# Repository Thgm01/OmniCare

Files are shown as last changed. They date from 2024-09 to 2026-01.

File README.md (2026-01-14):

# OmniCare — Robô Móvel Omnidirecional para Navegação Multi-Andares

> Repositório do Trabalho de Conclusão de Curso de Engenharia de Robôs - OmniCare




<p align="center">
  OmniCare
</p>

---

## 📚 Sumário
- [Visão Geral](#visão-geral)
- [Estrutura do Projeto](#instalação-e-build)
- [Como executar o robô de forma teleoperada](#como-executar-o-robô-de-forma-teleoperada)
- [Como executar o robô para mapear (SLAM ToolBox)](#como-executar-o-robô-para-mapear)
- [Como executar a stack do NAV2](#como-executar-a-stack-do-nav2)

- [Documentações](#documentações)
- [Autores](#👤-autores)
- [Licença](#📝-licença)

---
## Visão Geral

O **OmniCare** é um robô móvel omnidirecional desenvolvido para navegação autônoma em ambientes complexos, com capacidade de deslocamento entre **múltiplos andares** utilizando **elevadores reais**.  
O projeto envolve integração profunda de **ROS 2**, **STM32**, **percepção computacional**, **planejamento de movimento**, **manipulação**, além de uma arquitetura de software robusta baseada em máquina de estados.

## Estrutura do Projeto
 
```bash
.
├── firmware/ # Se concentra todos os firmwares utilizados 
├── hardware/ # Documentação e arquivos da parte eletrônica
├── mechanics/ # Arquivos CAD e modelagem mecânica
├── scripts/
│   ├── record_navigation.sh # Script para gravar a bag de navegação
│   ├── record_vision.sh # Script para gravar a bag de visão
│   ├── scripts.sh # Script para setup do robô
│   ├── setup.sh # Script para setup do robô
│   ├── startup.sh # Script que é rodado quando a jetson "boota"
│   └── sync_omnicare.sh # Script para rsync nootebook --> jetson
│
├── software/src/ # ROS 2 workspace
│   ├── omnicare_behavior/ # Contem o Behavior Manager (FSM)
│   ├── omnicare_bringup/ # Launch principal do OmniCare
│   ├── omnicare_control/ # Controle de movimento do robô
│   ├── omnicare_description/ # Descrição do robô (URDF/XACRO)
│   ├── omnicare_msgs/ # Definição de mensagens customizadas
│   ├── omnicare_navigation/ # Configuração do SLAM e NAV2
│   ├── omnicare_simulation/ # Simulação no Gazebo
│   └── omnicare_vision/ # Módulo de visão computacional
│
└── README.md # Este documento
```

## Instalação e Build

```bash
git clone https://github.com/Thgm01/OmniCare.git
cd OmniCare/software/
rosdep install --from-paths . -y --ignore-src
colcon build --symlink-install
source install/setup.bash
```

## Como executar o robô de forma teleoperada
A teleoperação do OmniCare pode ser feita **diretamente na Jetson** (via SSH) ou **remotamente do seu computador**, desde que ambos utilizem o mesmo **ROS_DOMAIN_ID**.

### **1 - Acesse a Jetson via SSH**
```bash
ssh robot@robot.local
```

### **2 - Inicie o robô (bringup completo)**  
Este comando inicializa os drivers, sensores, TFs e toda a estrutura necessária para operar o robô no mundo real.

```bash
ros2 launch omnicare_bringup load_real_robot.launch.py
```

### **3 - Teleoperação usando teclado**

Você pode rodar o teleop **localmente no seu PC** ou **dentro da Jetson via SSH**.

1. Configure no seu PC o mesmo `ROS_DOMAIN_ID` usado pela Jetson:
```bash
export ROS_DOMAIN_ID=<mesmo_da_jetson>
```

2. Execute o teleop do seu computador:
```bash
ros2 run teleop_twist_keyboard teleop_twist_keyboard
```

## Como executar o robô para mapear
O mapeamento do OmniCare pode ser feita **diretamente na Jetson** (via SSH) ou **remotamente do seu computador**, desde que ambos utilizem o mesmo **ROS_DOMAIN_ID**.

### **1 - Acesse a Jetson via SSH**
```bash
ssh robot@robot.local
```

### **2 - Inicie o robô (bringup completo)**  
Este comando inicializa os drivers, sensores, TFs e toda a estrutura necessária para operar o robô no mundo real.

```bash
ros2 launch omnicare_bringup load_real_robot.launch.py
```

### **3 - Teleoperação usando teclado**

Você pode rodar o teleop **localmente no seu PC** ou **dentro da Jetson via SSH**.

1. Configure no seu PC o mesmo `ROS_DOMAIN_ID` usado pela Jetson:
```bash
export ROS_DOMAIN_ID=<mesmo_da_jetson>
```

2. Execute o teleop do seu computador:
```bash
ros2 run teleop_twist_keyboard teleop_twist_keyboard
```

### **4 - Mapeamento usando o SLAM ToolBox**

Você pode rodar **localmente no seu PC** ou **dentro da Jetson via SSH**.

1. Configure no seu PC o mesmo `ROS_DOMAIN_ID` usado pela Jetson:
```bash
export ROS_DOMAIN_ID=<mesmo_da_jetson>
```

2. Execute o teleop do seu computador:
```bash
ros2 launch navigation_pkg mapping_slam_toolbox.launch.py
```

3. Após rodar o launch do SLAM ToolBox, abra o RViz2 no seu computador com essa configuração
```bash
software/src/omnicare_navigation/navigation_pkg/config/rviz/mapping_cartographer.rviz
```

## Como executar a stack do NAV2
A navegação do OmniCare é preferivel ser feita **em um notebook externo** por conta do processamento, é necessário que ambos utilizem o mesmo **ROS_DOMAIN_ID**.

### **1 - Acesse a Jetson via SSH**
```bash
ssh robot@robot.local
```

### **2 - Inicie o robô (bringup completo)**  
Este comando inicializa os drivers, sensores, TFs e toda a estrutura necessária para operar o robô no mundo real.

```bash
ros2 launch omnicare_bringup load_real_robot.launch.py
```

### **3 - Navegando usando a stack do NAV2**

É recomendado rodar **localmente no seu PC** por conta do processamento pesado de CPU.

1. Configure no seu PC o mesmo `ROS_DOMAIN_ID` usado pela Jetson:
```bash
export ROS_DOMAIN_ID=<mesmo_da_jetson>
```

2. Execute o teleop do seu computador:
```bash
ros2 launch navigation_pkg navigation2.launch.py
```

3. Após rodar o launch do NAV2, abra o RViz2 no seu computador com essa configuração
```bash
software/src/omnicare_navigation/navigation_pkg/config/rviz/navigation.rviz
``` 
## Documentações

A documentação do OmniCare está organizada de forma modular, abrangendo mecânica, hardware, firmware e software.  
Cada módulo possui sua própria pasta dedicada, permitindo uma navegação clara e objetiva.

---

### Documentação Mecânica
A pasta [`mechanics/`](mechanics/) contém:

- Modelos CAD completos do robô  
- Estrutura da base omnidirecional  
- Projeto do manipulador linear  
- Especificações de motores, rodas e sensores mecânicos  

---

### Documentação Hardware
A pasta [`hardware/`](hardware/) contém:

- Esquemáticos elétricos  
- Layout da arquitetura eletrônica  
- Detalhamento dos módulos embarcados  

---

### Documentação Software (ROS 2)

O software do OmniCare é composto por múltiplos pacotes ROS 2, cada um contendo suas características e funcionalidades.

### Pacotes ROS 2
---

### 🔹 [omnicare_behavior](software/src/omnicare_behavior/)
O pacote **omnicare_behavior** contem a máquina de estados responsável por coordenar toda a missão do robô. É ele quem controla o fluxo completo da navegação entre diferentes andares, integrando percepção, navegação, manipulação e troca de mapas. O Behavior Manager decide quando iniciar a navegação, alinhar ao elevador, interagir com o painel, trocar de mapa no momento correto e retomar o trajeto até o destino final.

---

### 🔹 [omnicare_bringup](software/src/omnicare_bringup/)
O pacote **omnicare_bringup** é responsável por inicializar todo o sistema do robô, tanto no ambiente real quanto no simulador. Ele carrega automaticamente os módulos essenciais, incluindo o ROS 2 Control, a comunicação com os microcontroladores (STM32), e os sensores embarcados, como o LiDAR. Em resumo, é o pacote que prepara todo o ecossistema do OmniCare para operação, garantindo que hardware, drivers e interfaces estejam corretamente configurados antes da execução dos módulos de navegação e comportamento.

---

### 🔹 [omnicare_control](software/src/omnicare_control/)
O **omnicare_control** é um conjunto de três pacotes que implementa toda a camada de controle de baixo nível do OmniCare. Ele integra a cinemática, a dinâmica e as interfaces de hardware do robô, permitindo que o sistema execute movimentos omnidirecionais de forma precisa e compatível com o ROS 2 Control e o movimento do manipulador.

---

### 🔹 [omnicare_description](software/src/omnicare_description/)

O **omnicare_description** é o pacote responsável por reunir toda a descrição física do OmniCare, incluindo o seu URDF completo, as malhas utilizadas para visualização e os plugins necessários para simulação e controle. Ele define a estrutura mecânica, sensores, atuadores e juntas do robô, garantindo que sua representação virtual seja fiel ao modelo real. Além disso, integra os plugins do Gazebo para simulação física e dos ROS 2 Control para conexão com controladores e interfaces de hardware, servindo como a base unificada para visualização, simulação e operação do robô tanto no ambiente virtual quanto no mundo real.

---

### 🔹 [omnicare_hri](software/src/omnicare_hri/)

O **omnicare_hri** engloba os pacotes dedicados à Interação Humano–Robô (HRI) no OmniCare. Ele é composto por um módulo responsável pelas animações faciais do robô — incluindo expressões exibidas na tela frontal, LEDs de sinalização e o buzzer — permitindo que o robô comunique estados e ações de forma mais amigável ao usuário. Complementando essa funcionalidade, o segundo pacote implementa uma interface para um controle remoto baseado em ESP32, possibilitando acionar comandos do robô de maneira simples.

---

### 🔹 [omnicare_msgs](software/src/omnicare_msgs/)

O **omnicare_msgs** é o pacote responsável por definir todas as mensagens customizadas utilizadas pelos diferentes módulos do OmniCare, incluindo topics, services e actions. Ele centraliza estruturas de dados específicas do projeto — como comandos de movimento, estados do comportamento, mensagens do manipulador, sinais de expressão e eventos da navegação multi-andares — garantindo comunicação padronizada e consistente entre os diversos nós do sistema.

---

### 🔹 [omnicare_navigation](software/src/omnicare_navigation/)
O **omnicare_navigation** reúne um conjunto de pacotes responsáveis por toda a camada de navegação do OmniCare. Ele inclui o pacote do LiDAR, que fornece os dados primários de percepção espacial, e o pacote da IMU, atualmente integrado ao sistema mas ainda não utilizado diretamente na navegação. O núcleo deste módulo é o navigation_pkg, que contém os launch files do NAV2, incluindo configuração de planejadores, BTs e parâmetros de navegação. Além disso, o conjunto oferece launchs específicos para mapeamento do ambiente, permitindo a criação e atualização de mapas utilizados pelo Nav2 e pelo AMCL.

---

### 🔹 [omnicare_simulation](software/src/omnicare_simulation/)
O **omnicare_simulation** reúne todos os recursos necessários para a simulação completa do OmniCare no Gazebo, incluindo launch files dedicados para iniciar o robô, seus sensores e o ambiente virtual. Além disso, o pacote implementa serviços auxiliares de teletransporte dentro do simulador para validação da navegação de multi-andares.

---

### 🔹 [omnicare_vision](software/src/omnicare_vision/)
O **omnicare_vision** concentra todos os pacotes relacionados ao sistema de visão do OmniCare. Ele inclui o usb_cam, que atua como driver da câmera e fornece o fluxo de imagens bruto; o floor_detector, responsável por realizar a inferência sobre o display do elevador e classificar corretamente o andar atual; e o dataset_generator, um pacote auxiliar utilizado para gerar datasets automaticamente a partir de rosbags.

## 👤 Autores

**Lucas Lagoeiro**  
Graduando em Engenharia de Robôs – Centro Universitário FEI  
Área: Programação e Elétrica   
[LinkedIn](https://www.linkedin.com/in/llagoeiro/) • [GitHub](https://github.com/LucasLagoeiro)

**Thiago Moura**  
Graduando em Engenharia de Automação e Controle – Centro Universitário FEI  
Área: Programação e Elétrica  
[LinkedIn](https://www.linkedin.com/in/thiago-t-moura/) • [GitHub](https://github.com/Thgm01)

**Massiel Blandy**  
Graduando em Engenharia de Automação e Controle – Centro Universitário FEI  
Área: Programação  
[LinkedIn](https://www.linkedin.com/in/massiel-blandy-ram%C3%B3n-65214829a/) • [GitHub](https://github.com/massiblandy)

**Júlia Hernandes**  
Graduanda em Engenharia Elétrica – Centro Universitário FEI  
Área: Elétrica  
[LinkedIn](https://www.linkedin.com/in/j%C3%BAlia-gagliera-hernandes-40545b221/) 

**Gustavo Rosell**  
Graduando em Engenharia de Automação e Controle – Centro Universitário FEI  
Área: Mecânica  
[LinkedIn](https://linkedin.com/in/gustavo-rosell) 

**Leonardo Quirino**  
Graduando em Engenharia de Robôs – Centro Universitário FEI  
Área: Mecânica  
[LinkedIn](https://www.linkedin.com/in/leonardo-quirino-353486218/)

## 📝 Licença

Este projeto está licenciado sob a Licença MIT.

Isso significa que você pode usar, copiar, modificar, mesclar, publicar, distribuir, sublicenciar e/ou vender cópias do software, desde que mantenha o aviso de copyright e a permissão de licença incluídos em todas as cópias ou partes substanciais do software.

Para mais detalhes, consulte o arquivo [LICENSE](LICENSE).

## 📝 TODO — Documentação dos Pacotes

A seguir está o checklist de pacotes do OmniCare que terão documentação detalhada seguindo o mesmo padrão adotado no `omnicare_behavior`.

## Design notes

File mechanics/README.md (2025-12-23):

# OmniCare Mechanics

O OmniCare foi projetado para operar em ambientes hospitalares, com ênfase em mobilidade omnidirecional, modularidade estrutural e compatibilidade com normas de circulação. 
A base possui arquitetura circular, construída com chapas de MDF e perfis de alumínio, permitindo a integração do sistema elétrico, do manipulador e de um compartimento de carga modular. 
O manipulador foi desenvolvido para interação com elevadores, contando com graus de liberdade translacionais e rotacional no efetuador final.

Nesta seção você encontrará todos os materiais relacionados ao desenvolvimento mecânico do robô, incluindo:

- Modelos CAD completos do robô;
- Estrutura da base omnidirecional;
- Projeto do manipulador;
- Especificações de motores e rodas.

Esses arquivos permitem entender a composição estrutural do robô, seus componentes principais e a lógica de montagem mecânica.

Os arquivos de montagem estão separadas nas cinco seguintes pastas: Base, Carga, Fixação, LED, Manipulador. 

### Base

A pasta base contem todas as peças que compõe a base omnidirecional do OmniCare. Nesta pasta estão todos os modelos das chapas MDF (pasta MDF) e dos perfis de alumínio (pasta Perfil de alumínio) usados para montar a estrutura do robô, além das chapas de alumínio que contornam o robô (pasta Alumínio. O modelo das rodas omnidirecionais estão contidos dentro desta pasta (pasta Roda), assim como os motores utilizados para seu acionamento (pasta Motor). Todas as peças especiais, que precisaram ser feitas por meio de impressão 3D, estão contidas nesta pasta (pasta Impresso). E, por fim, a pasta conta com modelos 3D de todos os itens comprados do robô, como o LiDAR e as baterias.

### Carga

A pasta carga é a responsável por guardar os modelos 3D do compartimento de carga do OmniCare. Sua divisão de subpastas é igual a divisão da pasta Base.

### LED

Dentro da pasta LED estão todos os arquivos utilizados para a confecção do difusor de LED do OmniCare. Mas não somente os modelos 3D estão nesta pasta, há dois arquivos de pesquisas referentes a interações humano-robô que discutem a importância das interações visuais (luzes) e interações auditivas (emissões de sons de alerta), essas pesquisas são de suma importância para a IHR do OmniCare.

### Manipulador

A pasta Manipulador está dividida em 4 subpastas principais. Dentro da pasta Estrutura, estão todas as peças desenvolvidas para o corpo do manipulador e as peças responsáveis pelo movimento vertical do manipulador. Já na pasta Elevador, estão as peças feitas para a base que acompanha o movimento vertical, base essa responsável por realizar o movimento horizontal do manipulador. A pasta Ferramenta conta com as peças feitas para a confecção da ferramenta, responsável por segurar a câmera do OmniCare e por pressionar os botões do elevador. A pasta Elementos de fixação conta com todos os parafusos, porcas e arruelas usadas para a fixação de todas as partes do manipulador.

### Fixação

Todos os elementos de fixação utilizados no OmniCare, desde parafusos à cantoneiras, se encontram dentro da pasta Fixação. Nesta pasta, também é possível encontrar os arquivos das normas dos itens, além das tabelas de dimensões.

O acesso às modelagens e documentos está disponível no link abaixo:
https://drive.google.com/drive/folders/1Ufkg-2wcXs-KffQ5NBY0fZA2kzGGDrn_?usp=drive_link

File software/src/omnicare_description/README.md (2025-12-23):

# OmniCare Description (`omnicare_description`)

O **`omnicare_description`** é o pacote responsável por concentrar toda a **descrição física e estrutural do OmniCare**, servindo como a base para **visualização, simulação e controle** do robô.  
Ele define como o robô “existe” dentro do ecossistema ROS 2, garantindo consistência entre o modelo físico, o simulador e os controladores.

---

## Considerações

A descrição do robô foi projetada para atender simultaneamente aos seguintes cenários:

- Visualização no **RViz**;
- Simulação física no **Gazebo**;
- Integração com o **ROS 2 Control**;
- Operação no robô real.

Para isso, o pacote foi estruturado de forma modular, permitindo ativar ou desativar plugins conforme o modo de execução (simulação ou real), sem a necessidade de manter múltiplas descrições distintas.

---

## Arquitetura Geral

O `omnicare_description` atua como o **núcleo descritivo** do sistema, fornecendo:

- Estrutura mecânica do robô;
- Relações cinemáticas entre links e juntas;
- Definição de sensores e atuadores;
- Interfaces necessárias para controle e simulação.

Todos os outros pacotes — navegação, controle, simulação e bringup — dependem diretamente dessa descrição. Ele segue essa estrutura de arquivos:
```bash
omnicare_description/
├─ launch/
│  └─ display.launch.py
│     └─ Launch para visualização do robô no RViz
│        (robot_state_publisher + joint_state_publisher + RViz)
│
├─ config/
│  └─ display.rviz
│     └─ Configuração padrão do RViz utilizada no display.launch.py
│
├─ urdf/
│  ├─ robot.xacro
│  │  └─ Arquivo principal da descrição do OmniCare
│  │     Define links, joints e inclui módulos conforme o modo
│  │     (simulação ou robô real)
│  │
│  ├─ robot.gazebo
│  │  └─ Plugins para simulação no Gazebo
│  │     (sensores e parâmetros físicos)
│  │
│  ├─ ros2_control.xacro
│  │  └─ Integração do robô real com o ROS 2 Control
│  │     Define hardware interface, joints e interfaces de comando
│  │
│  ├─ gazebo_control.xacro
│  │  └─ Integração do robô simulado com o ROS 2 Control
│  │     Utiliza o plugin gazebo_ros2_control (ñ utilizado)
│  │
│  └─ camera.xacro
│     └─ Definição dos frames e da geometria da câmera do robô
│
└─ meshes/
   └─ (Arquivos de malha e sensores)
      └─ Modelos 3D utilizados pelo URDF para visualização e colisão
```

---

## URDF / Xacro

A descrição do OmniCare é construída utilizando **URDF com Xacro**, o que permite:

- Parametrização de componentes;
- Reutilização de macros;
- Diferenciação entre **modo simulado** e **modo real**;
- Organização clara do modelo do robô.

O arquivo Xacro principal é responsável por incluir:
- Base omnidirecional;
- Rodas e juntas;
- Manipulador frontal;
- Sensores (ex.: LiDAR);
- Interfaces de controle.

---

## Integração com ROS 2 Control

A integração com o ROS 2 Control é definida diretamente no URDF por meio da tag `<ros2_control>`.  
Essa seção especifica como o sistema de controle se comunica com o hardware real, quais juntas são controladas e quais interfaces de comando e estado são utilizadas.

---

## Definição do Sistema ROS 2 Control

```xml
<ros2_control name="RealRobot" type="system">
```

- **`name="RealRobot"`**: identifica o sistema de controle do robô real.
- **`type="system"`**: indica que o plugin implementa leitura de estados e escrita de comandos diretamente no hardware.

---

## Hardware Interface

```xml
<hardware>
    <plugin>omnidrive_stm32/OmniDriveSTM32</plugin>
```

O plugin **`OmniDriveSTM32`** (encontrado no **`omnicare_control/omnidrive_stm32/`**) implementa a Hardware Interface do ROS 2 Control, sendo responsável por:

- Enviar comandos de velocidade ao STM32;
- Ler feedback dos encoders;
- Atualizar os estados das juntas no ROS 2.

---

## Parâmetros de Hardware

```xml
<param name="left_wheel_name">wheel2_speed</param>
<param name="right_wheel_name">wheel1_speed</param>
<param name="back_wheel_name">wheel3_speed</param>
```

Mapeamento entre juntas do URDF e rodas físicas do robô, essa informação tem que bater com o arquivo de configuração do controlador ([omnidirectional_controllers](../omnicare_control/omnidirectional_controllers/config/omnidirectional_controller.yaml)).

```xml
<param name="loop_rate">30</param>
```

Frequência de atualização da interface (Hz).

```xml
<param name="device">/dev/usb-user</param>
<param name="baud_rate">115200</param>
<param name="timeout_ms">1000</param>
```

Parâmetros da comunicação serial com o STM32.

```xml
<param name="enc_counts_per_rev">12770</param>
```

Resolução do encoder utilizada para cálculo de velocidade e posição (relacionado ao nosso motor - se trocar, vai precisar alterar esse parâmetro).

---

## Definição das Juntas

Cada roda é definida como uma junta controlada:

```xml
<joint name="wheel1_speed">
    <command_interface name="velocity" />
    <state_interface name="position" />
    <state_interface name="velocity" />
</joint>
```

- **Command Interface**: `velocity` (utilizando na função de **write** do [Hardware Inteface](../omnicare_control/omnidrive_stm32/hardware/diffbot_system.cpp))
- **State Interfaces**: `position` e `velocity` (utilizando na função de **read** do [Hardware Inteface](../omnicare_control/omnidrive_stm32/hardware/diffbot_system.cpp))

O mesmo padrão é utilizado para as três rodas omnidirecionais.

---

## Fluxo de Funcionamento

1. Nav2, teleoperação ou Behavior Manager publicam `cmd_vel`;
2. O `controller_manager` recebe o comando;
3. O controlador omnidirecional calcula:
   - cinemática;
   - odometria;
   - velocidades individuais das rodas;
4. O ROS 2 Control envia comandos para o STM32;
5. O STM32 executa o controle de baixo nível (PID/PWM);
6. O feedback dos encoders retorna ao ROS 2;
7. Estados e odometria alimentam Nav2 e localização.

---
## Integração com Gazebo

Para simulação, o `omnicare_description` inclui **plugins do Gazebo** responsáveis por:

- Simular sensores (LiDAR, estados das juntas, etc.);
- Aplicar dinâmica e física ao modelo;
- Permitir interação com o ambiente virtual.

Esses plugins são habilitados apenas quando o robô é executado em modo simulado, mantendo a descrição compatível com o robô real.

---

## Visualização no RViz

A descrição fornecida por este pacote é utilizada diretamente pelo **RViz**, permitindo:

- Visualização da geometria do robô;
- Acompanhamento da árvore de TFs;
- Monitoramento do estado das juntas;
- Depuração visual durante desenvolvimento e testes.

Para conseguir visualiza-lo basta apenas rodar:
```bash
ros2 launch omnicare_description display.launch.py
```

---

## Integração com Outros Pacotes

O `omnicare_description` é utilizado diretamente por:

- **`omnicare_bringup`** — carregamento da descrição durante a inicialização;
- **`omnicare_control`** — definição das juntas e transmissões para controle;
- **`omnicare_simulation`** — spawn do robô no Gazebo;
- **`omnicare_navigation`** — referência de frames (`base_link`, `odom`, `map`);
s
---

## Papel no Sistema

O **`omnicare_description`** é o pacote que garante que **todas as camadas do OmniCare falem a mesma “língua física”**.  
Ele assegura que o robô visto no simulador, controlado pelo ROS 2 Control e operando no mundo real compartilhe a mesma estrutura, cinemática e referências, sendo essencial para a robustez e a escalabilidade do sistema.

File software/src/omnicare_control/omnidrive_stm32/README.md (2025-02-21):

# omnidrive_stm32

This node is designed to provide a ros2_control hardware interface for an Arduino running firmware from `ros_arduino_bridge`.
It is designed to be used with a `diff_drive_controller` from `ros2_control`.
It is expected to communicate via serial and to have two motors, each with velocity control and position/velocity feedback.

It is based on the diffbot example from [ros2_control demos](https://github.com/ros-controls/ros2_control_demos/tree/master/example_2).

For a tutorial on how to develop a hardware interface like this, check out the video below:

https://youtu.be/J02jEKawE5U

## To Do

- [ ] Document changes from earlier versions
- [ ] Document usage and parameters
- [ ] Clean up remaining connections to original demo code
- [ ] Add license etc (in the meantime, do whatever you want with it)

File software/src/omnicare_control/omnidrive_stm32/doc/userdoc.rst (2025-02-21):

.. _ros2_control_demos_example_2_userdoc:

*********
DiffBot
*********

*DiffBot*, or ''Differential Mobile Robot'', is a simple mobile base with differential drive.
The robot is basically a box moving according to differential drive kinematics.

For *example_2*, the hardware interface plugin is implemented having only one interface.

- The communication is done using proprietary API to communicate with the robot control box.
- Data for all joints is exchanged at once.

The *DiffBot* URDF files can be found in ``description/urdf`` folder.

Tutorial steps
--------------------------

1. To check that *DiffBot* description is working properly use following launch commands

   .. code-block:: shell

    ros2 launch omnidrive_stm32 view_robot.launch.py

   .. warning::
    Getting the following output in terminal is OK: ``Warning: Invalid frame ID "odom" passed to canTransform argument target_frame - frame does not exist``.
    This happens because ``joint_state_publisher_gui`` node need some time to start.

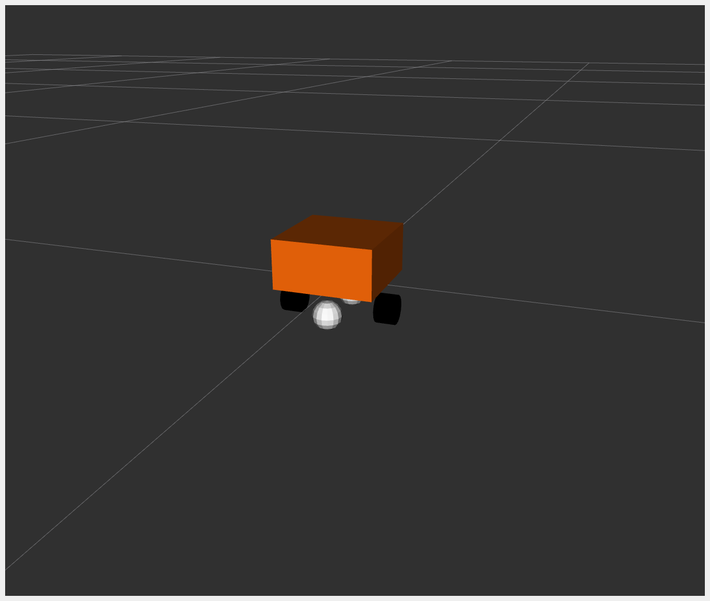
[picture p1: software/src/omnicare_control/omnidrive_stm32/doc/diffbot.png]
Differential Mobile Robot
   

2. To start *DiffBot* example open a terminal, source your ROS2-workspace and execute its launch file with

   .. code-block:: shell

    ros2 launch omnidrive_stm32 diffbot.launch.py

   The launch file loads and starts the robot hardware, controllers and opens *RViz*.
   In the starting terminal you will see a lot of output from the hardware implementation showing its internal states.
   This excessive printing is only added for demonstration. In general, printing to the terminal should be avoided as much as possible in a hardware interface implementation.

   If you can see an orange box in *RViz* everything has started properly.
   Still, to be sure, let's introspect the control system before moving *DiffBot*.

3. Check if the hardware interface loaded properly, by opening another terminal and executing

   .. code-block:: shell

    ros2 control list_hardware_interfaces

   You should get

   .. code-block:: shell

    command interfaces
          left_wheel_joint/velocity [available] [claimed]
          right_wheel_joint/velocity [available] [claimed]
    state interfaces
          left_wheel_joint/position
          left_wheel_joint/velocity
          right_wheel_joint/position
          right_wheel_joint/velocity

   The ``[claimed]`` marker on command interfaces means that a controller has access to command *DiffBot*.

4. Check if controllers are running

   .. code-block:: shell

    ros2 control list_controllers

   You should get

   .. code-block:: shell

    diffbot_base_controller[diff_drive_controller/DiffDriveController] active
    joint_state_broadcaster[joint_state_broadcaster/JointStateBroadcaster] active

5. If everything is fine, now you can send a command to *Diff Drive Controller* using ROS 2 CLI interface:

   .. code-block:: shell

    ros2 topic pub --rate 30 /diffbot_base_controller/cmd_vel_unstamped geometry_msgs/msg/Twist "linear:
      x: 0.7
      y: 0.0
      z: 0.0
    angular:
      x: 0.0
      y: 0.0
      z: 1.0"

   You should now see an orange box circling in *RViz*.
   Also, you should see changing states in the terminal where launch file is started.

   .. code-block:: shell

    [OmniDriveSTM32]: Got command 43.33333 for 'left_wheel_joint'!
    [OmniDriveSTM32]: Got command 50.00000 for 'right_wheel_joint'!

Files used for this demos
#########################

  - Launch file: `diffbot.launch.py <https://github.com/ros-controls/ros2_control_demos/tree/master/example_2/bringup/launch/diffbot.launch.py>`__
  - Controllers yaml: `diffbot_controllers.yaml <https://github.com/ros-controls/ros2_control_demos/tree/master/example_2/bringup/config/diffbot_controllers.yaml>`__
  - URDF file: `diffbot.urdf.xacro <https://github.com/ros-controls/ros2_control_demos/tree/master/example_2/description/urdf/diffbot.urdf.xacro>`__

    + Description: `diffbot_description.urdf.xacro <https://github.com/ros-controls/ros2_control_demos/tree/master/example_2/description/urdf/diffbot_description.urdf.xacro>`__
    + ``ros2_control`` tag: `diffbot.ros2_control.xacro <https://github.com/ros-controls/ros2_control_demos/tree/master/example_2/description/ros2_control/diffbot.ros2_control.xacro>`__

  - RViz configuration: `diffbot.rviz <https://github.com/ros-controls/ros2_control_demos/tree/master/example_2/description/rviz/diffbot.rviz>`__

  - Hardware interface plugin: `diffbot_system.cpp <https://github.com/ros-controls/ros2_control_demos/tree/master/example_2/hardware/diffbot_system.cpp>`__

Controllers from this demo
##########################

- ``Joint State Broadcaster`` (`ros2_controllers repository <https://github.com/ros-controls/ros2_controllers/tree/master/joint_state_broadcaster>`__): `doc <https://control.ros.org/master/doc/ros2_controllers/joint_state_broadcaster/doc/userdoc.html>`__
- ``Diff Drive Controller`` (`ros2_controllers repository <https://github.com/ros-controls/ros2_controllers/tree/master/diff_drive_controller>`__): `doc <https://control.ros.org/master/doc/ros2_controllers/diff_drive_controller/doc/userdoc.html>`__

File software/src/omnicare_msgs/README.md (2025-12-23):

# OmniCare Messages (`omnicare_msgs`)

O **`omnicare_msgs`** é o pacote responsável por centralizar todas as **mensagens customizadas** utilizadas no projeto OmniCare.  
Ele define os tipos de dados usados para comunicação entre nós ROS 2 por meio de **topics**, **services** e **actions**, garantindo padronização, clareza e integração entre os diferentes subsistemas do robô.

---

## Considerações

Em um sistema robótico complexo como o OmniCare, a comunicação entre módulos precisa ser:

- Bem definida;
- Consistente ao longo de todo o projeto;
- Fácil de manter e expandir.

Por esse motivo, todas as mensagens customizadas foram agrupadas em um único pacote, evitando duplicações e facilitando a evolução do sistema.

---

## Tipos de Interfaces

O `omnicare_msgs` contém três tipos principais de definições:

### Messages (`msg`)
Mensagens utilizadas para comunicação assíncrona via tópicos, geralmente para:
- Estados do robô;
- Comandos simples;
- Publicação contínua de informações.

---

### Services (`srv`)
Serviços utilizados para chamadas síncronas, quando é necessário:
- Enviar uma requisição;
- Aguardar uma resposta imediata.

São comuns em comandos pontuais, como inicializações ou mudanças de estado.

A maioria dos serviços criados são utilizadas mensagens customizadas para aumentar a flexibilidade do que mandar.

---

### Actions (`action`)
Actions são utilizadas para operações de **longa duração**, permitindo:
- Envio de um objetivo (*goal*);
- Recebimento de *feedback* contínuo;
- Notificação de conclusão (*result*).

No OmniCare, actions são fundamentais para tarefas como:
- Navegação multi-andares;

---

## Integração com Outros Pacotes

Este pacote é utilizado por praticamente todo o sistema, incluindo:

- **`omnicare_behavior`** — definição de actions para missões e estados;
- **`omnicare_navigation`** — troca de informações de navegação;
- **`omnicare_control`** — comandos e estados de controle;
- **`omnicare_expression`** — acionamento de expressões e sinalizações;
- **`omnicare_hri`** — interação humano–robô.

---

## Papel no Sistema

O **`omnicare_msgs`** garante que todos os módulos do OmniCare se comuniquem de forma clara, consistente e organizada.  
Ele é um elemento fundamental para a escalabilidade do projeto, permitindo adicionar novas funcionalidades sem comprometer a integração entre os subsistemas existentes.

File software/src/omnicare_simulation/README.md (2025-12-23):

# OmniCare Simulation (`omnicare_simulation`)

O **`omnicare_simulation`** é o pacote responsável por toda a **infraestrutura de simulação do OmniCare**, permitindo testar e validar o comportamento do robô em um ambiente virtual antes da execução no robô real.  
Ele integra o OmniCare ao **Gazebo**, fornece *launch files* dedicados e implementa **serviços auxiliares**, como o teletransporte do robô entre posições e andares.

Este pacote é essencial para desenvolvimento, depuração e validação segura das funcionalidades de navegação, controle e comportamento.

---

## Considerações

A simulação foi projetada para:

- Reproduzir o comportamento do robô real com alta fidelidade;
- Permitir testes rápidos e repetíveis;
- Facilitar o desenvolvimento de navegação multi-andares;
- Reduzir riscos durante a fase de desenvolvimento.

Sempre que possível, a mesma lógica utilizada no robô real é reaproveitada na simulação, alterando apenas os *plugins* e interfaces específicas do ambiente virtual.

---

## Arquitetura Geral

O `omnicare_simulation` atua como uma camada intermediária entre:

- A **descrição do robô** (`omnicare_description`);
- O **stack de navegação** (`navigation_pkg`);
- O **Behavior Manager** (`omnicare_behavior`);
- O **simulador Gazebo**.

Ele garante que todos esses módulos operem de forma coordenada dentro do ambiente simulado.

---

## Arquitetura do Pacote

```bash
omnicare_simulation/
│ 
├─ launch/
│  └─ simulation.launch.py        # Launch principal da simulação
│
├─ omnicare_simulation/
│  └─ teleport_service.py         # Serviço de teletransporte no Gazebo 
│
└─ simulation
   ├─ models/ # alguns models para o mundo do Gazebo
   ├─ stl/ # mapas criados em STL, como da FEI e do HU-USP
   └─ words/ # os mundos do Gazebo, tanto da FEI, quanto da USP
```

---

## Funcionalidades Principais

- Inicialização completa do OmniCare em simulação;
- Spawn do robô no Gazebo com sensores simulados;
- Integração com o ROS 2 Control em modo simulado;
- Serviços de **teletransporte**, utilizados para simular troca de andares;
- Suporte a testes de navegação, comportamento e percepção.

---

## Serviço de Teletransporte

O pacote implementa um **serviço de teletransporte** que permite reposicionar o robô diretamente no ambiente do Gazebo.  
Esse recurso é fundamental para a simulação de navegação multi-andares, pois substitui fisicamente o uso de elevadores reais.

O Behavior Manager utiliza esse serviço para:
- Reposicionar o robô após a troca de mapa;
- Garantir coerência entre a pose simulada e o novo andar.

---

## Como Executar a Simulação

Exemplo genérico de execução:

```bash
ros2 launch omnicare_simulation simulation.launch.py
```
Para spawnar o robo no ambiente, deve se executar o bringupd do simulation robot:
```bash
ros2 launch omnicare_simulation simulation.launch.py
```

Após a inicialização, o robô estará disponível no Gazebo e pronto para receber comandos de navegação, teleoperação ou missões automáticas via Behavior Manager.

---

## Integração com Outros Pacotes

O `omnicare_simulation` integra-se diretamente com:

- **omnicare_description** — descrição física e plugins do robô;
- **navigation_pkg** — navegação e mapeamento;
- **omnicare_behavior** — controle de missões e FSM;
- **omnicare_control** — controladores em modo simulado;
- **omnicare_msgs** — troca de mensagens, serviços e actions.

---

## Papel no Sistema

O **`omnicare_simulation`** permite que todo o sistema OmniCare seja desenvolvido e validado de forma segura, controlada e reprodutível.  
Ele é a principal ferramenta para testes de navegação multi-andares, integração entre módulos e avaliação do comportamento do robô antes da execução em ambientes reais.

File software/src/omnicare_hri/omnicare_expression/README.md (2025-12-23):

# OmniCare Expression (`omnicare_expression`)

O **`omnicare_expression`** é o pacote responsável pela **expressividade e sinalização do OmniCare**, utilizando uma tela frontal com animações (rosto do robô) e LEDs/Buzzer para tornar a presença do robô mais amigável e comunicativa.  
O pacote permite executar vídeos/animações de forma sincronizada com ações do robô, ajudando a transmitir estados e intenções durante demonstrações e missões.

---

## Considerações

As animações exibidas no OmniCare são **pré-renderizadas** (vídeos gerados previamente) e reproduzidas localmente na unidade de processamento do robô.  
O sistema foi implementado com foco em:

- Baixa latência e reprodução estável;
- Sincronização de ações do robô com timestamps do vídeo;
- Uso em testes e demonstrações públicas.

Embora contribua para aceitação social do robô, este pacote não caracteriza HRI bidirecional, atuando como uma camada de **expressão visual**, apenas para apresentação do projeto em ocasiões específicas.

---

## Arquitetura Geral

O pacote reproduz um vídeo principal e chama serviços sincronizadas [(**`expressionsNode.py`**)](omnicare_expression/expressionService.py) conforme o tempo do vídeo, como:

- Movimentações da base para demonstração da cinemática omnidirecional;
- Acionamento do manipulador;
- LEDs e buzzer.

A sincronização ocorre por **marcadores temporais** definidos no próprio código [(**`expressionsNode.py`**)](omnicare_expression/expressionsNode.py).

O pacote também faz a interface com o microcontrolador responsável pelos LEDs e Buzzer  [(**`alertNode.py`**) ](omnicare_expression/alertNode.py)

---

## Componentes do Pacote

- Nó principal de reprodução de animações;
- Vídeos e assets gráficos;
- Arquivo de configuração com labels/timestamps;
- Integração opcional com serviços do robô.

---

## Como Executar

Para inicializar o rosto amigável e a interface com o microcontrolador deve-se rodar esse launch:

```bash
ros2 launch omnicare_expression expression_system.launch.py
```

Quando iniciado, o vídeo inicia em estado de idle, aguardando o tópico **`/omnicare/hri/idle_done`**, portanto deve-se chama-lo via CLI e aguardar alguns segundos para começar a apresentação.

```bash
ros2 topic pub -1 /omnicare/hri/idle_done std_msgs/msg/String "{data: True}"
```

---

## Papel no Sistema

O **`omnicare_expression`** fornece ao OmniCare uma camada de **presença social e comunicação visual**, permitindo apresentações, sinalização de estados e sincronização de ações, tornando o robô mais compreensível e amigável.

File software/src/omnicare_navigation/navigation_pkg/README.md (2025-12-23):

# OmniCare Navigation (`navigation_pkg`)

O **`navigation_pkg`** é o pacote responsável por toda a **infraestrutura de navegação autônoma do OmniCare**.  
Ele concentra os *launch files* do Nav2, configurações de mapeamento e localização, mapas dos ambientes, definição de checkpoints e nós auxiliares que viabilizam a navegação **multi-andares** integrada ao Behavior Manager.

Este pacote é um dos núcleos do sistema, pois conecta percepção, controle e comportamento em uma navegação robusta e reprodutível.

---

## Considerações

A navegação do OmniCare foi projetada para:

- Operar em ambientes reais e simulados;
- Suportar troca dinâmica de mapas;
- Executar trajetórias baseadas em checkpoints pré-definidos;
- Integrar-se ao Nav2, SLAM Toolbox, robot_localization e AMCL;
- Permitir extensões para novos ambientes e andares sem alterar código-fonte.

---

## Arquitetura do Pacote

```bash
navigation_pkg/
├─ launch/
│  ├─ navigation2.launch.py
│  │  └─ Launch principal do Nav2, responsável por subir o stack de navegação
│  │     (planners, controllers, costmaps, BT e recovery behaviors)
│  │
│  ├─ mapping_slam_toolbox.launch.py
│  │  └─ Launch para mapeamento utilizando SLAM Toolbox
│  │
│  └─ mapping_cartographer.launch.py
│     └─ Launch alternativo para mapeamento com Cartographer (ñ utilizado)
│
├─ config/
│  ├─ nav/
│  │  ├─ nav2_params.yaml
│  │  │  └─ Parâmetros principais do Nav2 (planners, controllers, costmaps, BT)
│  │  │
│  │  ├─ nav2_params_MPPI.yaml
│  │  │  └─ Variante de configuração utilizando o controlador MPPI
│  │  │
│  │  ├─ sim_nav2_params.yaml
│  │  │  └─ Parâmetros específicos para navegação em simulação
│  │  │
│  │  ├─ ekf.yaml
│  │  │  └─ Configuração do robot_localization (EKF) - obs: é utilizando o pacote
│  │  │     do robot localization no bringup do robo real, por isso desse config
│  │  │
│  │  ├─ slam_toolbox.yaml
│  │  │  └─ Parâmetros do SLAM Toolbox
│  │  │
│  │  └─ box_filter.yaml
│  │     └─ Filtros aplicados ao LiDAR para aumentar robustez da navegação
│  │
│  ├─ maps/
│  │  ├─ FEI/
│  │  │  └─ Mapas do ambiente FEI
│  │  │
│  │  ├─ HU_USP/
│  │  │  └─ Mapas do ambiente HU-USP
│  │  │
│  │  └─ simulation/
│  │     └─ Mapas utilizados em simulação
│  │
│  └─ checkpoint/
│     └─ Arquivos JSON contendo sequências de checkpoints (poses)
│        organizadas por ambiente e andar
│
└─ navigation_pkg/
   ├─ checkpointsService.py
   │  └─ Serviço responsável por dar start, parar e salvar checkpoints ao sistema
   │
   ├─ floorManagerNode.py
   │  └─ Nó de gerenciamento de contexto de andar e mapas (utilizado apenas para depuração)
   │
   ├─ switchFloorService.py
   │  └─ Serviço para troca de andar/mapa durante a missão (Behavior Manager)
   │
   ├─ enterElevatorAction.py
   │  └─ Action relacionada à navegação associada ao uso do elevador (Foi desenvolvida, 
   │     mas ñ utilizada no Behavior Manager)
   │
   ├─ poseFromTFNode.py
   │  └─ Nó auxiliar para obtenção da pose a partir da árvore TF (URDF)
   │
   └─ amclOrientationNode.py
      └─ Nó auxiliar para ajuste e consistência da orientação do AMCL
```

---

## Funcionamento Geral

1. O Nav2 é inicializado;
2. O mapa correspondente é carregado;
3. Os checkpoints são lidos;
4. O robô navega sequencialmente entre checkpoints;
5. Em missões multi-andares, ocorre troca dinâmica de mapa;
6. A navegação é retomada até o destino final.

---

## Integração com Outros Pacotes

- omnicare_behavior  
- omnicare_control  
- omnicare_description  
- omnicare_vision  
- omnicare_msgs  

---

## Papel no Sistema

O **`navigation_pkg`** fornece serviços e actions para o alto nível (behavior_manager), viabilizando a navegação segura e a troca dinâmica de mapas em ambientes multi-andares.

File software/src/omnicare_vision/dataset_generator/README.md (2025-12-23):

# OmniCare Dataset Generator (`dataset_generator`)

O **`dataset_generator`** é o pacote responsável por **gerar automaticamente datasets de visão computacional** a partir de dados gravados durante a operação do OmniCare, principalmente **rosbags** contendo imagens da câmera do robô.  
Ele foi desenvolvido para apoiar o treinamento e a melhoria contínua dos modelos utilizados no pacote **`floor_detector`**.

---

## Objetivo do Pacote

Durante testes reais ou simulados, o robô grava rosbags contendo imagens da câmera frontal.  
O `dataset_generator` permite transformar esses dados brutos em **datasets organizados**, prontos para:

- Anotação manual (ex.: Roboflow);
- Treinamento de modelos de detecção ou classificação;
- Avaliação e validação de novos modelos.

Esse processo reduz drasticamente o esforço manual de coleta de dados.

---

## Arquitetura Geral

O pacote funciona de forma **offline**, ou seja, não participa da execução do robô em tempo real.  
Seu fluxo principal é:

1. Leitura de uma rosbag contendo imagens;
2. Extração dos frames da câmera;
3. Salvamento das imagens em diretórios organizados;
4. Geração de estrutura compatível com ferramentas de anotação.

---

## Arquitetura do Pacote

```bash
dataset_generator/
├─ config/
│  └─ dataset_generator_config.yaml      # Configurações do processo de geração
│
└─ dataset_generator/
   ├─ dataset_generator.py               # Script principal de geração do dataset
   └─ get_parameters.py                  # Funções auxiliares 

```

---

## Funcionamento

O usuário fornece como entrada:

- O caminho para a rosbag;
- O tópico de imagem desejado (ex.: `camera1/image_raw`);
- Parâmetros como taxa de amostragem e diretório de saída.

O pacote então percorre a rosbag e salva os frames em formato de imagem, organizados de forma consistente.

---

## Exemplo de Uso

Exemplo genérico de execução:

```bash
ros2 launch dataset_generator dataset_generator.launch.py
```

> Os argumentos exatos podem variar conforme a implementação do script principal.

---

## Integração com Outros Pacotes

O `dataset_generator` é utilizado principalmente em conjunto com:

- **floor_detector** — geração de dados para treinamento dos modelos;
- **omnicare_vision / usb_cam** — origem das imagens;
- Ferramentas externas de anotação (ex.: Roboflow).

---

## Papel no Sistema

O **`dataset_generator`** viabiliza a criação de datasets representativos do ambiente real do robô, permitindo a evolução contínua dos modelos de visão do OmniCare.  
Ele é um componente fundamental para garantir robustez e generalização dos algoritmos de percepção utilizados na navegação multi-andares.

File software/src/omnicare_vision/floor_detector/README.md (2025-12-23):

# OmniCare Floor Detector (`floor_detector`)

O **`floor_detector`** é o pacote responsável pelo **reconhecimento automático do andar** em que o OmniCare se encontra, por meio de **visão computacional aplicada ao display do elevador**.  
Esse pacote é um componente-chave para a navegação **multi-andares**, fornecendo ao sistema a informação necessária para validar a troca de andar e sincronizar a mudança de mapas.

---

## Considerações

O reconhecimento do andar é um problema crítico em ambientes reais, onde informações como sensores de posição vertical nem sempre estão disponíveis ou são confiáveis.  
Por isso, o OmniCare utiliza uma abordagem baseada em **visão**, diretamente alinhada com a percepção do ambiente humano.

O pacote foi projetado para:
- Operar em ambientes reais e simulados;
- Ser robusto a variações de iluminação e ângulo;
- Reduzir falsos positivos na detecção do andar;
- Minimizar consumo computacional quando não está ativo.

---

## Arquitetura Geral

O `floor_detector` implementa um pipeline de visão em **duas etapas**:

1. **Detecção do display do elevador** na imagem completa da câmera;
2. **Classificação do dígito do andar** a partir do recorte do display.

Essa arquitetura reduz custo computacional e aumenta a confiabilidade da classificação.

---

## Arquitetura do Pacote

```bash
floor_detector/
├─ launch/
│  └─ floor_detector.launch.py        # Launch do sistema de detecção
│
├─ config/
│  └─ floor_detector_config.yaml      # Parâmetros gerais do detector (como os pesos da rede treinada do HU e da FEI)
│
├─ weights/                           # Se concentra todos os pesos treinados
│
└─ floor_detector/
   ├─ floor_detector_node.py          # Nó principal que faz a detecção e classificação dos andares
   └─ get_parameters.py               # Pega os parametros do config
```

---

## Pipeline de Visão

### 1️⃣ Detecção do Display

O primeiro modelo identifica a **região do display do elevador** na imagem da câmera frontal do robô.  
Essa etapa retorna uma *bounding box* que delimita a área de interesse.

---

### 2️⃣ Classificação do Andar

A região recortada do display é então utilizada como entrada para o segundo modelo, responsável por **classificar o dígito do andar**.  
O resultado é publicado como uma estimativa do andar atual no tópico: **`omnicare/floor_detector/info`**

---

## Estratégia de Robustez

Para reduzir erros de classificação, o sistema:
- Executa múltiplas inferências consecutivas;
- Valida a consistência do resultado ao longo do tempo;
- Apenas confirma o andar quando um número mínimo de classificações iguais é atingido.

Essa lógica é utilizada pelo Behavior Manager para decidir quando a troca de mapa pode ser realizada com segurança.

---

## Como Executar

Para iniciar o detector de andar, execute:

```bash
ros2 launch floor_detector floor_detector.launch.py
```

Porém a inferencia fica desativada para aumentar a autonomia da bateria. Para ativa-lá, basta apenas chamar o serviço desse nó:

```bash
ros2 service call /omnicare/floor_detector/OnOffNode omnicare_msgs/srv/OnOffNode "{activate: True}"
```

---

## Integração com Outros Pacotes

O `floor_detector` integra-se diretamente com:

- **omnicare_behavior** — validação da troca de andar;
- **navigation_pkg** — sincronização da mudança de mapa;
- **omnicare_vision / usb_cam** — aquisição de imagens da câmera;
- **omnicare_msgs** — troca de mensagens customizadas.

---

## Papel no Sistema

O **`floor_detector`** fornece ao OmniCare a percepção necessária para operar de forma autônoma em ambientes multi-andares.  
Ele garante que a troca de mapas ocorra apenas quando o robô realmente atingir o andar correto, aumentando a robustez e a segurança da navegação.

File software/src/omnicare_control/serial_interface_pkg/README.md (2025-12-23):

# Serial Interface Package (`serial_interface_pkg`)

O **`serial_interface_pkg`** é o pacote responsável por implementar uma **interface de comunicação serial direta** entre o OmniCare e o **manipulador frontal**, sem utilizar o pipeline do **ROS 2 Control**.  
Ele foi desenvolvido para atender às necessidades específicas do manipulador, permitindo um controle mais simples, direto e flexível.

Este pacote complementa a arquitetura de controle do OmniCare, coexistindo com o ROS 2 Control utilizado na base móvel.

---

## Considerações

O manipulador do OmniCare possui requisitos diferentes da base omnidirecional, como:

- Movimentos discretos e bem definidos;
- Sequências de ação simples (ex.: estender, recolher, pressionar botão);
- Comunicação direta com o microcontrolador do manipulador.

Por esse motivo, optou-se por uma **interface serial customizada**, desacoplada do ROS 2 Control, reduzindo complexidade e facilitando a integração e depuração.

---

## Arquitetura Geral

O `serial_interface_pkg` atua como uma **ponte direta** entre o ROS 2 e o microcontrolador responsável pelo manipulador.

Fluxo simplificado:

1. Um nó ROS 2 envia um comando para o manipulador;
2. O `serial_interface_pkg` converte esse comando para o protocolo serial definido;
3. O microcontrolador executa a ação solicitada;
4. (Opcional) O microcontrolador retorna um feedback de estado.

Esse fluxo garante comunicação simples e determinística para as ações do manipulador.

---

## Funcionalidades Principais

- Comunicação serial direta com o microcontrolador do manipulador;
- Envio de comandos de acionamento (ex.: estender, recolher, parar);
- Possibilidade de leitura de feedback ou estados;
- Parametrização de porta serial e baudrate;
- Independência do ROS 2 Control.

---

## Integração com Outros Pacotes

O `serial_interface_pkg` é utilizado principalmente por:

- **`omnicare_hri`** — integração com ações de interação humano–robô, quando aplicável no presentation do robo;
- **Firmware do manipulador** — responsável por executar os comandos recebidos via serial, respeitando o sensor de fim de curso.

Esse pacote atua como elo direto entre o comportamento de alto nível e o hardware do manipulador.

---

## Como Executar

Para iniciar a interface serial do manipulador, execute:

```bash
ros2 launch serial_interface_pkg serial_interface.launch.py robot_part:=manip
```

Antes de executar, verifique se:

- A porta serial correta está configurada nos arquivos de configuração (**`/config/*.yaml`**);
- O microcontrolador do manipulador está energizado;
- O firmware do manipulador está em execução.

---

## Papel no Sistema

O **`serial_interface_pkg`** é responsável por garantir que o manipulador do OmniCare possa ser controlado de forma **simples, confiável e independente** da base móvel.  
Ele complementa a arquitetura do sistema ao permitir uma comunicação direta e específica para o manipulador, mantendo o restante do sistema modular e organizado.

## Observação

O USB do Arduino ñ esta linkado com algum nome de USB padrão, então possivelmente possa mudar do **`ttyACM0`**

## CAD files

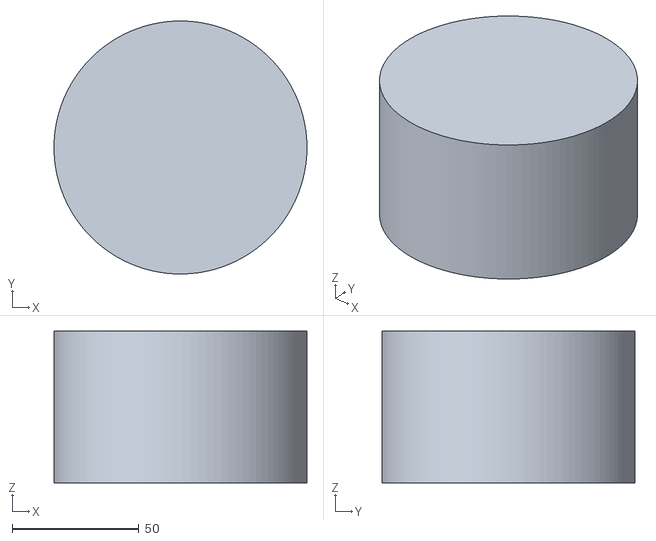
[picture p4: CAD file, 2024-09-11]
software/src/omnicare_description/meshes/lidar_1.stl
100.0 x 100.0 x 60.0

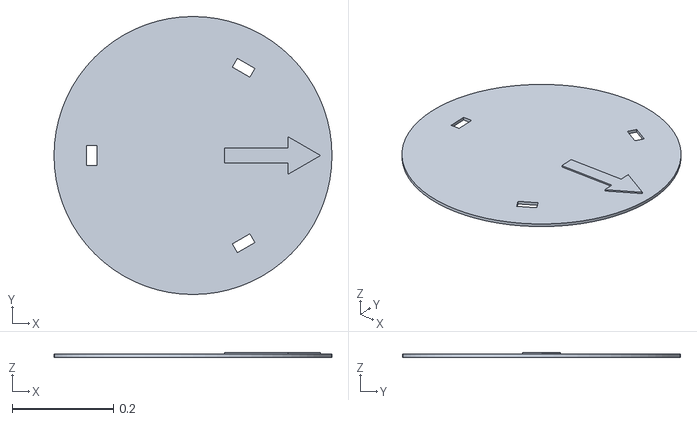
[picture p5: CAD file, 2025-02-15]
software/src/omnicare_description/meshes/omni/mdf.stl
0.55 x 0.55 x 0.009

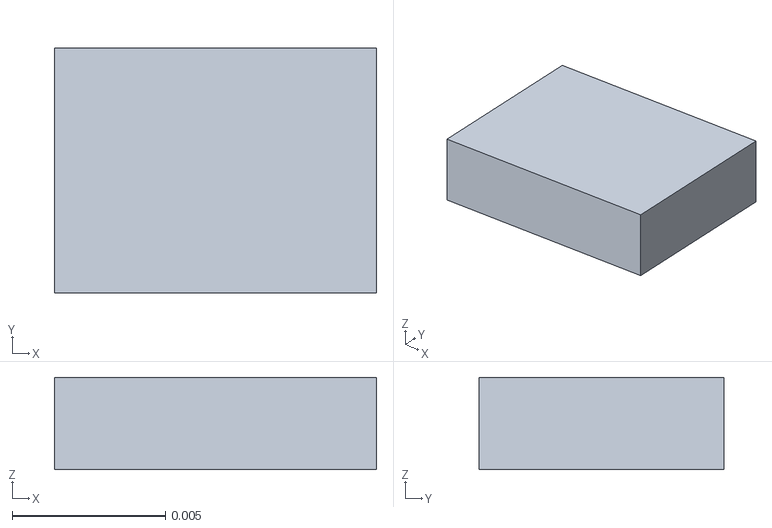
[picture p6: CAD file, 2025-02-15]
software/src/omnicare_description/meshes/omni/imu.stl
0.0105 x 0.008 x 0.003

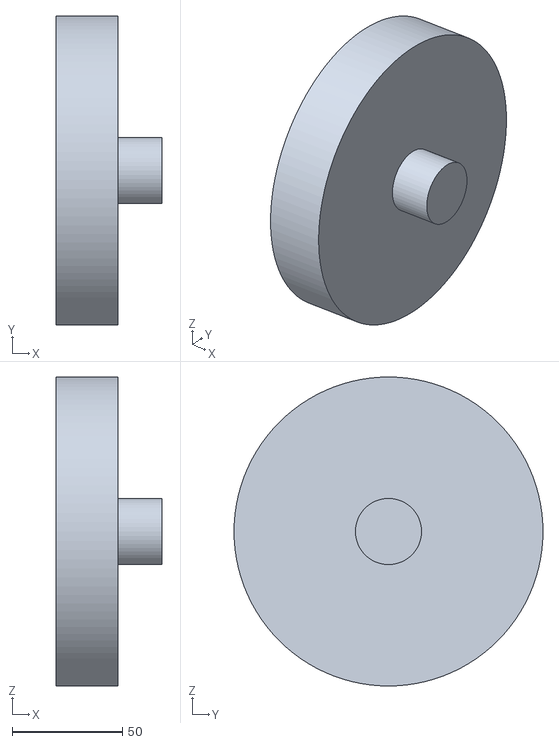
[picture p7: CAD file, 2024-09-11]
software/src/omnicare_description/meshes/rear_wheel_1.stl
48.0 x 140.0 x 140.0

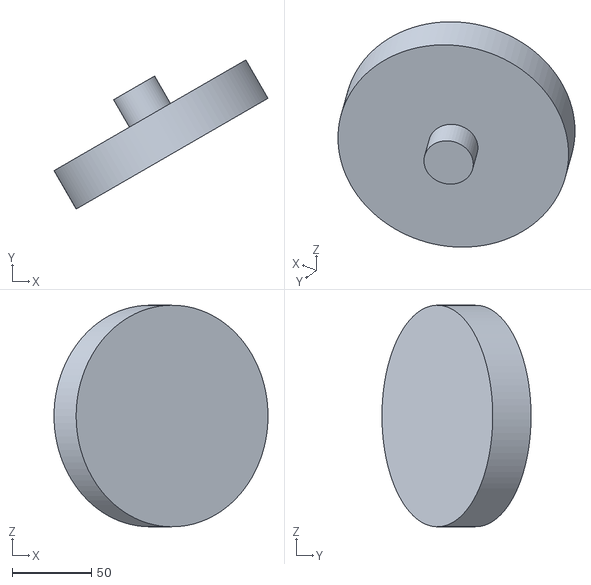
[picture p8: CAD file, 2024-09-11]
software/src/omnicare_description/meshes/front_right_wheel_1.stl
135.2 x 94.2 x 140.0

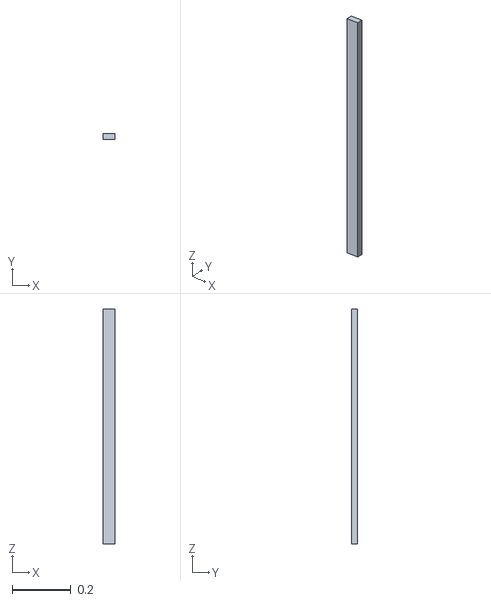
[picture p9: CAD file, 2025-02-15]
software/src/omnicare_description/meshes/omni/perfil_coluna.stl
0.04 x 0.02 x 0.8

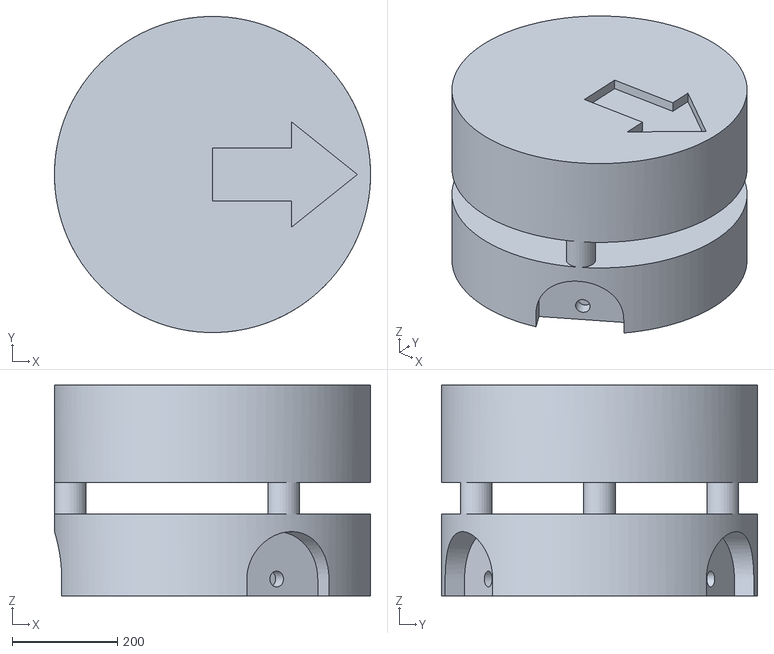
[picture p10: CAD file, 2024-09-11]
software/src/omnicare_description/meshes/base_link.stl
600.0 x 599.8 x 400.0

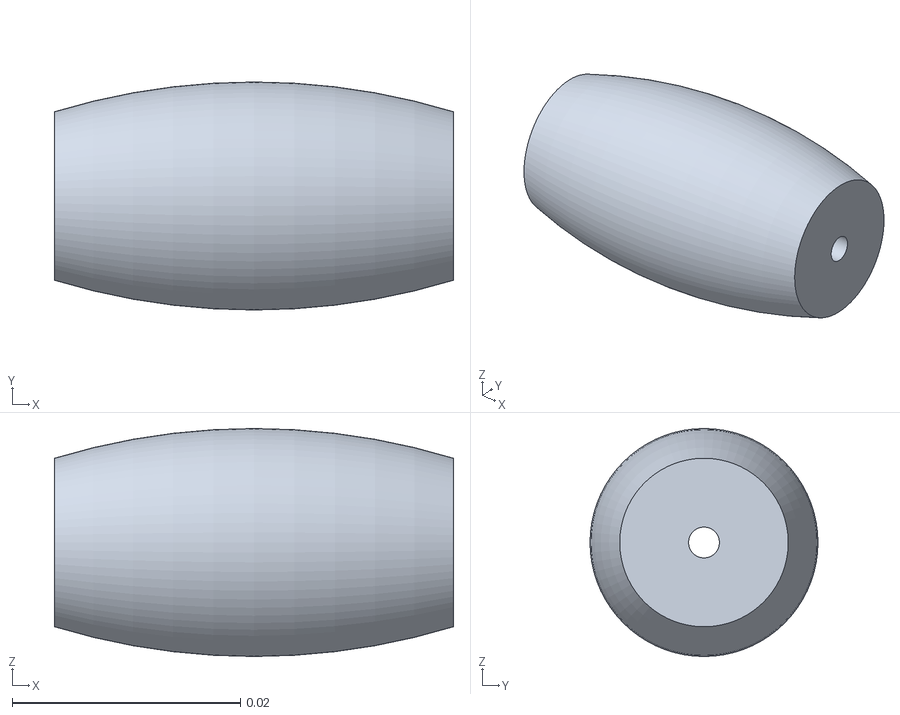
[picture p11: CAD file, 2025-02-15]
software/src/omnicare_description/meshes/omni/rolete.stl
0.035 x 0.02 x 0.02

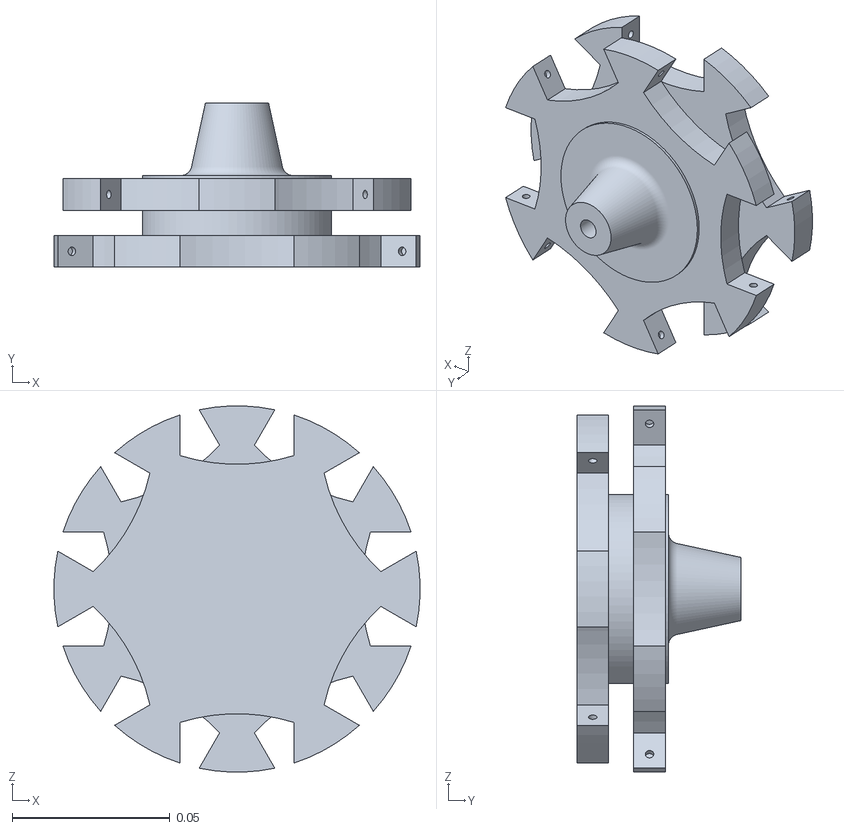
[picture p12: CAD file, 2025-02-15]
software/src/omnicare_description/meshes/omni/roda.stl
0.116 x 0.052 x 0.116

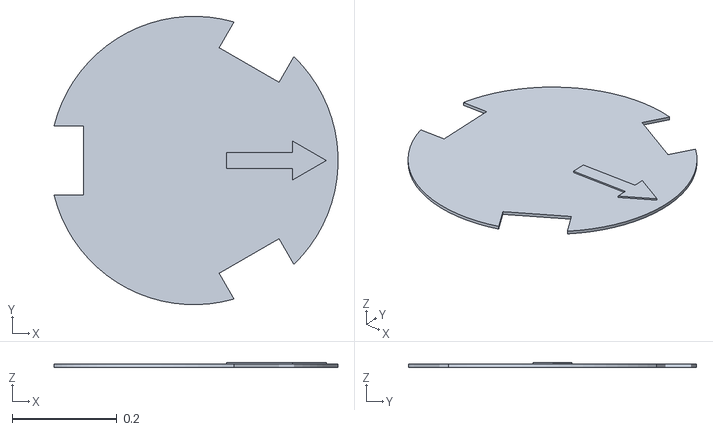
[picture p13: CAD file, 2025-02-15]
software/src/omnicare_description/meshes/omni/mdf_motores.stl
0.542 x 0.55 x 0.009

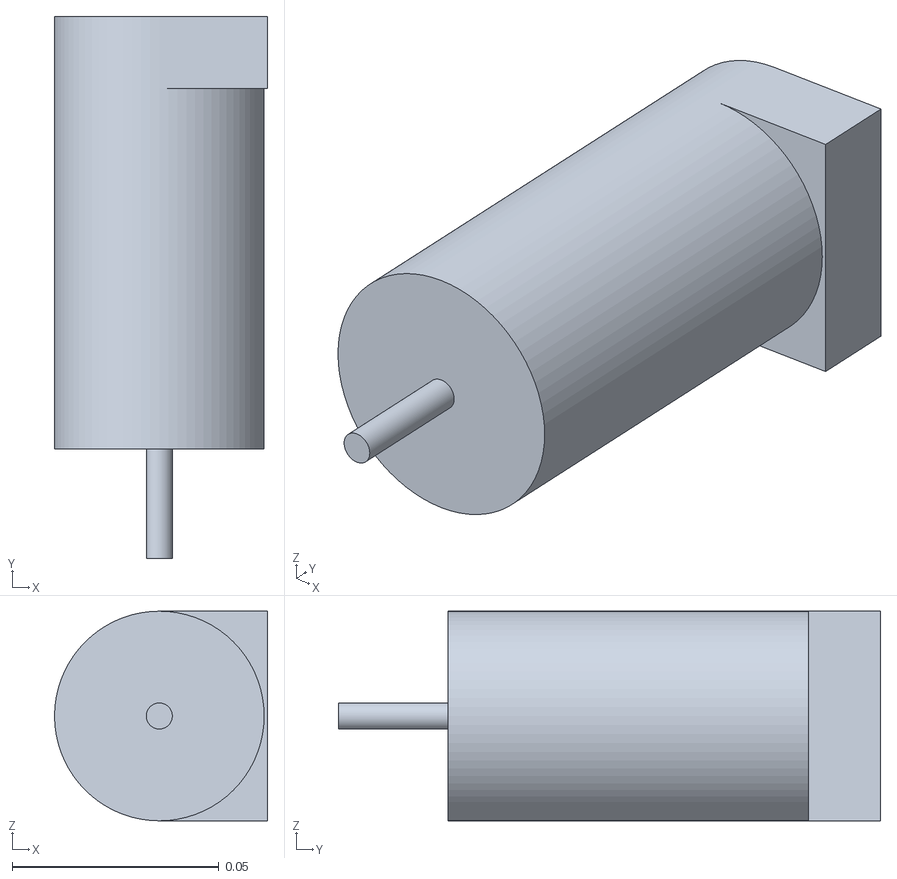
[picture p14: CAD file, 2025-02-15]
software/src/omnicare_description/meshes/omni/motor.stl
0.0515 x 0.131 x 0.0507

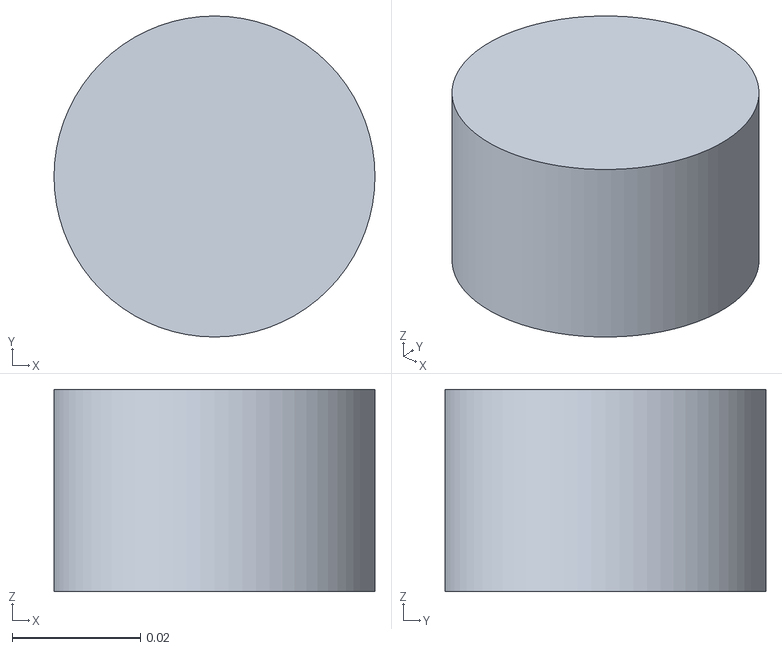
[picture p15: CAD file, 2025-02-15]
software/src/omnicare_description/meshes/omni/lidar.stl
0.05 x 0.05 x 0.0315

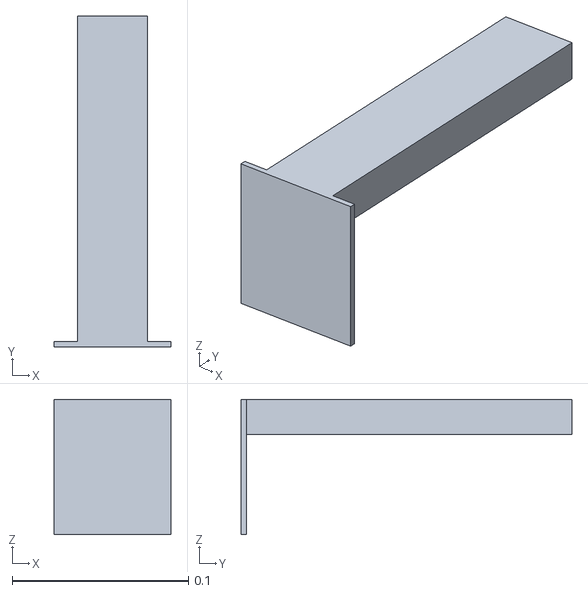
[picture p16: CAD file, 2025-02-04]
software/src/omnicare_description/meshes/omni/perfil_motores.stl
0.0663 x 0.188 x 0.0767

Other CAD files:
software/src/omnicare_description/meshes/front_left_wheel_1.stl
software/src/omnicare_description/meshes/cute_cube.blend

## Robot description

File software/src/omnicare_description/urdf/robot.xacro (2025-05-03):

<?xml version="1.0"?>
<robot name="robot" xmlns:xacro="http://www.ros.org/wiki/xacro">

    <xacro:arg name="sim_mode" default="false" />

    <xacro:if value="$(arg sim_mode)">
        <xacro:include filename="$(find omnicare_description)/urdf/robot.gazebo" />
    </xacro:if>
    <xacro:unless value="$(arg sim_mode)">
        <xacro:include filename="$(find omnicare_description)/urdf/ros2_control.xacro" />
    </xacro:unless>


    <link name="lidar_link"></link>
    <joint name="lidar_to_base" type="fixed">
        <parent link="base_link" />
        <child link="lidar_link" />
        <origin rpy="0.0 0 3.14" xyz="0 0 0" />
    </joint>


    <joint name="base_footprint_to_base_link" type="fixed">
        <parent link="base_footprint" />
        <child link="base_link" />
        <origin rpy="0.0 0 0" xyz="0 0 0" />
    </joint>
    <link name="base_footprint"></link>


    <link name="base_link"></link>
    <joint name="base_link_to_base" type="fixed">
        <parent link="base_link" />
        <child link="base" />
        <origin rpy="0.0 0 1.57" xyz="0 0 0" />
    </joint>
    <link name="base">
        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
        <inertial>
            <origin xyz="-2.5725654066226820008e-17 -0.00072713798642877675634 0.1130692369102963557" rpy="0 0 0" />
            <mass value="6.6083023665046667361" />
            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
        </inertial>
    </link>

    <link name="roda">
        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
        <inertial>
            <origin xyz="2.488178870261553677e-17 -5.0324958787843994577e-18 -0.036248827632811911337" rpy="0 0 0" />
            <mass value="0.17417946931200009586" />
            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
        </inertial>
    </link>

    <link name="rolete">
        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
        <inertial>
            <origin xyz="-1.8827844672617356948e-33 8.8261553917125876786e-19 -0.017500000000000064115" rpy="0 0 0" />
            <mass value="0.0095254397280000006887" />
            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
        </inertial>
    </link>

    <joint name="w1_external_1_passive" type="continuous">
        <origin xyz="0.01750000000000022024 -0.050000000000000002776 -0.046999999999999930722" rpy="-3.141592653589793116 -1.570796326794896558 0" />
        <parent link="roda" />
        <child link="rolete" />
        <axis xyz="0 0 1" />
        <limit effort="1" velocity="20" />
        <joint_properties friction="0.0" />
    </joint>

    <link name="rolete_2">
        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
        <inertial>
            <origin xyz="2.4286128663675299322e-17 1.5253801182852536392e-20 -0.017500000000000053707" rpy="0 0 0" />
            <mass value="0.0095254397280000006887" />
            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
        </inertial>
    </link>

    <joint name="w1_external_2_passive" type="continuous">
        <origin xyz="0.052051270189221954254 -0.009844555433772231301 -0.047000000000000041744" rpy="1.570796326794896558 4.1633363423452281929e-17 2.6179938779914921909" />
        <parent link="roda" />
        <child link="rolete_2" />
        <axis xyz="0 0 1" />
        <limit effort="1" velocity="20" />
        <joint_properties friction="0.0" />
    </joint>

    <link name="rolete_3">
        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
        <inertial>
            <origin xyz="-5.5511151231257827021e-17 1.5253801182858512794e-20 -0.017500000000000067585" rpy="0 0 0" />
            <mass value="0.0095254397280000006887" />
            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
        </inertial>
    </link>

    <joint name="w1_external_3_passive" type="continuous">
        <origin xyz="0.052051270189221968132 0.0098445554337722868121 -0.047000000000000041744" rpy="-1.570796326794896558 4.163336342345265787e-17 -2.6179938779914921909" />
        <parent link="roda" />
        <child link="rolete_3" />
        <axis xyz="0 0 1" />
        <limit effort="1" velocity="20" />
        <joint_properties friction="0.0" />
    </joint>

    <link name="rolete_4">
        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
        <inertial>
            <origin xyz="-1.8827844672617356948e-33 1.5253801182855310935e-20 -0.017500000000000064115" rpy="0 0 0" />
            <mass value="0.0095254397280000006887" />
            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
        </inertial>
    </link>

    <joint name="w1_external_4_passive" type="continuous">
        <origin xyz="0.01750000000000022024 0.050000000000000002776 -0.046999999999999930722" rpy="-3.141592653589793116 -1.570796326794896558 0" />
        <parent link="roda" />
        <child link="rolete_4" />
        <axis xyz="0 0 1" />
        <limit effort="1" velocity="20" />
        <joint_properties friction="0.0" />
    </joint>

    <link name="rolete_5">
        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
        <inertial>
            <origin xyz="2.7755575615628907348e-17 -5.5495897430074969875e-17 -0.017500000000000053707" rpy="0 0 0" />
            <mass value="0.0095254397280000006887" />
            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
        </inertial>
    </link>

    <joint name="w1_external_5_passive" type="continuous">
        <origin xyz="-0.034551270189221897078 0.040155444566227743719 -0.046999999999999930722" rpy="1.570796326794896558 9.7144514654709209156e-17 2.6179938779914921909" />
        <parent link="roda" />
        <child link="rolete_5" />
        <axis xyz="0 0 1" />
        <limit effort="1" velocity="20" />
        <joint_properties friction="0.0" />
    </joint>

    <link name="rolete_6">
        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
        <inertial>
            <origin xyz="-1.0408340855860839485e-17 1.5253801182855816492e-20 -0.017500000000000060646" rpy="0 0 0" />
            <mass value="0.0095254397280000006887" />
            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
        </inertial>
    </link>

    <joint name="w1_external_6_passive" type="continuous">
        <origin xyz="-0.034551270189221897078 -0.040155444566227743719 -0.046999999999999986233" rpy="-1.570796326794896558 4.163336342345242984e-17 -2.6179938779914930791" />
        <parent link="roda" />
        <child link="rolete_6" />
        <axis xyz="0 0 1" />
        <limit effort="1" velocity="20" />
        <joint_properties friction="0.0" />
    </joint>

    <link name="rolete_7">
        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
        <inertial>
            <origin xyz="-2.7755575615628907348e-17 6.954147705090087065e-18 -0.017500000000000060646" rpy="0 0 0" />
            <mass value="0.0095254397280000006887" />
            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
        </inertial>
    </link>

    <joint name="w1_internal_1_passive" type="continuous">
        <origin xyz="0.0098445554337722885468 -0.052051270189221947315 -0.02899999999999994249" rpy="0.52359877559829937077 -1.570796326794896558 0" />
        <parent link="roda" />
        <child link="rolete_7" />
        <axis xyz="0 0 1" />
        <limit effort="1" velocity="20" />
        <joint_properties friction="0.0" />
    </joint>

    <link name="rolete_8">
        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
        <inertial>
            <origin xyz="-1.3877787807814456755e-17 -2.7740321814446059445e-17 -0.017500000000000043299" rpy="0 0 0" />
            <mass value="0.0095254397280000006887" />
            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
        </inertial>
    </link>

    <joint name="w1_internal_2_passive" type="continuous">
        <origin xyz="0.050000000000000016653 -0.017500000000000019013 -0.028999999999999970246" rpy="-1.570796326794896558 1.035468818874435832e-17 3.141592653589793116" />
        <parent link="roda" />
        <child link="rolete_8" />
        <axis xyz="0 0 1" />
        <limit effort="1" velocity="20" />
        <joint_properties friction="0.0" />
    </joint>

    <link name="rolete_9">
        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
        <inertial>
            <origin xyz="6.826351802735963352e-34 1.5253801182852948662e-20 -0.017500000000000071054" rpy="0 0 0" />
            <mass value="0.0095254397280000006887" />
            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
        </inertial>
    </link>

    <joint name="w1_internal_3_passive" type="continuous">
        <origin xyz="0.0098445554337722469135 0.052051270189221926499 -0.028999999999999998002" rpy="-0.5235987755982990377 -1.570796326794896558 0" />
        <parent link="roda" />
        <child link="rolete_9" />
        <axis xyz="0 0 1" />
        <limit effort="1" velocity="20" />
        <joint_properties friction="0.0" />
    </joint>
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

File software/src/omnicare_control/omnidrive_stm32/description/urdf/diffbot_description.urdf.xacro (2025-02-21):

<?xml version="1.0"?>
<robot xmlns:xacro="http://www.ros.org/wiki/xacro">

  <xacro:macro name="diffbot" params="prefix">

  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
  <xacro:property name="PI" value="3.1415926535897931"/>
  <xacro:property name="base_mass" value="0.3" /> 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
  <xacro:property name="base_width" value="0.1" />
  <xacro:property name="base_length" value="0.1" />
  <xacro:property name="base_height" value="0.05" />
  <xacro:property name="wheel_mass" value="0.3" /> 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
  <xacro:property name="wheel_len" value="0.020" />
  <xacro:property name="wheel_radius" value="0.015" />
  <xacro:property name="caster_wheel_mass" value="0.1" /> 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
  <xacro:property name="caster_wheel_radius" value="0.015" />
  <xacro:property name="z_offset" value="-${base_height/2}" /> 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
  <link name="${prefix}base_link">
    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

    <inertial>
      <origin xyz="0 0 0" rpy="0 0 0"/>
      <mass value="${base_mass}"/>
      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
      </inertial>
    </link>

    <joint name="${prefix}left_wheel_joint" type="continuous">
      <parent link="${prefix}base_link"/>
      <child link="${prefix}left_wheel"/>
      <origin xyz="0 -${base_width/2} ${z_offset}" rpy="0 0 0"/>
      <axis xyz="0 1 0"/>
      <dynamics damping="0.2"/>
    </joint>

    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
    <link name="${prefix}left_wheel">
      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

      <inertial>
        <origin xyz="0 0 0" rpy="${PI/2} 0 0"/>
        <mass value="${wheel_mass}"/>
        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
        </inertial>
      </link>

    <joint name="${prefix}right_wheel_joint" type="continuous">
      <parent link="${prefix}base_link"/>
      <child link="${prefix}right_wheel"/>
      <origin xyz="0 ${base_width/2} ${z_offset}" rpy="0 0 0"/>
      <axis xyz="0 1 0"/>
      <dynamics damping="0.2"/>
    </joint>

    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
    <link name="${prefix}right_wheel">
      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

      <inertial>
        <origin xyz="0 0 0" rpy="${PI/2} 0 0"/>
        <mass value="${wheel_mass}"/>
        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
        </inertial>
      </link>

    <joint name="${prefix}caster_frontal_wheel_joint" type="fixed">
      <parent link="${prefix}base_link"/>
      <child link="${prefix}caster_frontal_wheel"/>
      <origin xyz="${base_width/2 - caster_wheel_radius} 0 ${z_offset}" rpy="0 0 0"/>
    </joint>

    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
    <link name="${prefix}caster_frontal_wheel">
      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

      <inertial>
        <origin xyz="0 0 0" rpy="0 0 0"/>
        <mass value="${caster_wheel_mass}"/>
        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
        </inertial>
      </link>

    <joint name="${prefix}caster_rear_wheel_joint" type="fixed">
      <parent link="${prefix}base_link"/>
      <child link="${prefix}caster_rear_wheel"/>
      <origin xyz="${-base_width/2 + caster_wheel_radius} 0 ${z_offset}" rpy="0 0 0"/>
    </joint>

    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
    <link name="${prefix}caster_rear_wheel">
      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

      <inertial>
        <origin xyz="0 0 0" rpy="0 0 0"/>
        <mass value="${caster_wheel_mass}"/>
        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
        </inertial>
      </link>

  </xacro:macro>

</robot>

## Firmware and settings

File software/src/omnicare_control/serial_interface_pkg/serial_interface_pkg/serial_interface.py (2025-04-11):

import rclpy
from rclpy.node import Node
import serial
import struct

from omnicare_msgs.msg import MotorsData
from omnicare_msgs.msg import MotorsPWM

class InterfacePublisher(Node):

    def __init__(self):
        super().__init__('setial_interface_publisher')
        
        # TODO: Colocar .rules
        self.usb_port = "/dev/usb-user"  # Substitua pelo nome da sua porta USB
        self.baud_rate = 115200           # Taxa de comunicação

        self.motors_data_publisher_ = self.create_publisher(MotorsData, 'motors_data', 10)
        self.motors_data_publisher_

        self.motors_pwm_subscriber_ = self.create_subscription(MotorsPWM, 'motors_pwm', self.motors_pwm_callback, 10)
        self.motors_pwm_subscriber_
        self.pwm_data = MotorsPWM()

        timer_period = 0.01  # seconds
        self.timer = self.create_timer(timer_period, self.timer_callback)

        try:
            self.ser = serial.Serial(self.usb_port, self.baud_rate, timeout=1)
        except serial.SerialException as e:
            print(f"Erro ao acessar a porta {self.usb_port}: {e}")
            self.ser = None



    def timer_callback(self):
        motors_data_msg = MotorsData()

        if(self.ser == None):
            try:
                self.ser = serial.Serial(self.usb_port, self.baud_rate, timeout=1)
                print(f"Conectado à porta {self.usb_port} com baud rate {self.baud_rate}")
                print("Pressione Ctrl+C para sair.\n")

            except serial.SerialException as e:
                print(f"Erro ao acessar a porta {self.usb_port}: {e}")
                self.ser = None
        else:
            try:
                # values = (self.pwm_data.data[MotorsPWM.MOTOR_0], self.pwm_data.data[MotorsPWM.MOTOR_1], self.pwm_data.data[MotorsPWM.MOTOR_2])
                
                # TODO: Reesrever essa função para ele conseguir mandar também os valores
                # data = struct.pack('<hhh', *values)
                # self.ser.write(data)

                 # Convert ROS2 message to a simple string (CSV format)
 

                pwm_string = f"m {self.pwm_data.data[MotorsPWM.MOTOR_0]} {self.pwm_data.data[MotorsPWM.MOTOR_1]} {self.pwm_data.data[MotorsPWM.MOTOR_2]}\n"
 


 

                # Send over serial
 

                self.ser.write(pwm_string.encode())
 


 

                self.get_logger().info(f"Sent over serial: {pwm_string.strip()}")

                self.get_logger().debug(f'PWM Data: {self.pwm_data.data[MotorsPWM.MOTOR_0]:03} / {self.pwm_data.data[MotorsPWM.MOTOR_1]:03} / {self.pwm_data.data[MotorsPWM.MOTOR_2]:03}' )

                # raw_data = self.ser.read(12)  # Lê 3 bytes enviados pelo STM32
                linha = self.ser.readline().decode('utf-8').strip()  # Lê 4 bytes enviados pelo STM32
                self.get_logger().info(f'{linha}')
                valores = list(map(int, linha.split()))
                print(valores)

                motors_data_msg.motor_speed = valores[0]
                motors_data_msg.motor_error = valores[1]
                motors_data_msg.motor_dt = valores[2]
                motors_data_msg.motor_pwm = valores[3]

                # #publicando a data no tópico
                self.motors_data_publisher_.publish(motors_data_msg)

                # Limpa o buffer logo após a leitura
                self.ser.reset_input_buffer()
            except serial.SerialException as e:
                self.ser = None

    def motors_pwm_callback(self, msg):
        self.pwm_data = msg
        self.get_logger().info(f'PWM Data: {self.pwm_data.data[MotorsPWM.MOTOR_0]:03} / {self.pwm_data.data[MotorsPWM.MOTOR_1]:03} / {self.pwm_data.data[MotorsPWM.MOTOR_2]:03}' )


def main(args=None):
    rclpy.init(args=args)

    minimal_publisher = InterfacePublisher()

    rclpy.spin(minimal_publisher)

    # Destroy the node explicitly
    # (optional - otherwise it will be done automatically
    # when the garbage collector destroys the node object)
    minimal_publisher.destroy_node()
    rclpy.shutdown()


if __name__ == '__main__':
    main()

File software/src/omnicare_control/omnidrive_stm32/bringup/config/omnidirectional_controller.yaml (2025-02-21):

controller_manager:
  ros__parameters:
    update_rate: 30  # Hz
    # use_sim_time: true

    joint_state_broadcaster:
      type: joint_state_broadcaster/JointStateBroadcaster

    omnidirectional_controller:
      type: omnidirectional_controllers/OmnidirectionalController

omnidirectional_controller:
  ros__parameters:
    wheel_names: 
      - wheel2_speed
      - wheel1_speed
      - wheel3_speed

    robot_radius: 0.6
    wheel_radius: 0.140
    gamma: 30.0 # angle between body fixed y axis and the normal of wheel3

    publish_rate: 50.0
    odom_frame_id: odom
    base_frame_id: base_link
    pose_covariance_diagonal : [0.001, 0.001, 0.001, 0.001, 0.001, 0.01]
    twist_covariance_diagonal: [0.001, 0.001, 0.001, 0.001, 0.001, 0.01]
    odom_numeric_integration_method: runge_kutta2

    open_loop: true
    enable_odom_tf: true

    cmd_vel_timeout: 0.5
    use_stamped_vel: false

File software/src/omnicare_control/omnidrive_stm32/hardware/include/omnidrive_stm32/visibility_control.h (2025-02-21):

// Copyright 2021 ros2_control Development Team
//
// Licensed under the Apache License, Version 2.0 (the "License");
// you may not use this file except in compliance with the License.
// You may obtain a copy of the License at
//
//     http://www.apache.org/licenses/LICENSE-2.0
//
// Unless required by applicable law or agreed to in writing, software
// distributed under the License is distributed on an "AS IS" BASIS,
// WITHOUT WARRANTIES OR CONDITIONS OF ANY KIND, either express or implied.
// See the License for the specific language governing permissions and
// limitations under the License.

/* This header must be included by all rclcpp headers which declare symbols
 * which are defined in the rclcpp library. When not building the rclcpp
 * library, i.e. when using the headers in other package's code, the contents
 * of this header change the visibility of certain symbols which the rclcpp
 * library cannot have, but the consuming code must have inorder to link.
 */

#ifndef omnidrive_stm32__VISIBILITY_CONTROL_H_
#define omnidrive_stm32__VISIBILITY_CONTROL_H_

// This logic was borrowed (then namespaced) from the examples on the gcc wiki:
//     https://gcc.gnu.org/wiki/Visibility

#if defined _WIN32 || defined __CYGWIN__
#ifdef __GNUC__
#define omnidrive_stm32_EXPORT __attribute__((dllexport))
#define omnidrive_stm32_IMPORT __attribute__((dllimport))
#else
#define omnidrive_stm32_EXPORT __declspec(dllexport)
#define omnidrive_stm32_IMPORT __declspec(dllimport)
#endif
#ifdef omnidrive_stm32_BUILDING_DLL
#define omnidrive_stm32_PUBLIC omnidrive_stm32_EXPORT
#else
#define omnidrive_stm32_PUBLIC omnidrive_stm32_IMPORT
#endif
#define omnidrive_stm32_PUBLIC_TYPE omnidrive_stm32_PUBLIC
#define omnidrive_stm32_LOCAL
#else
#define omnidrive_stm32_EXPORT __attribute__((visibility("default")))
#define omnidrive_stm32_IMPORT
#if __GNUC__ >= 4
#define omnidrive_stm32_PUBLIC __attribute__((visibility("default")))
#define omnidrive_stm32_LOCAL __attribute__((visibility("hidden")))
#else
#define omnidrive_stm32_PUBLIC
#define omnidrive_stm32_LOCAL
#endif
#define omnidrive_stm32_PUBLIC_TYPE
#endif

#endif  // omnidrive_stm32__VISIBILITY_CONTROL_H_

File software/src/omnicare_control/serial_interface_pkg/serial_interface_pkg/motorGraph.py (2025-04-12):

import serial
import struct
import threading
import matplotlib.pyplot as plt
import matplotlib.animation as animation
from collections import deque

# Configurar a porta serial
ser = serial.Serial('/dev/usb-user', 115200, timeout=1)

# Buffers de dados
max_len = 250
velocidade = deque(maxlen=max_len)
erro = deque(maxlen=max_len)
pwm = deque(maxlen=max_len)
amostras = deque(maxlen=max_len)

contador = 0

def ler_dados():
    global contador
    while True:
        try:
            linha = ser.readline().decode('utf-8').strip()  # Lê 4 bytes enviados pelo STM32
            partes = list(map(int, linha.split()))
            if len(partes) == 4:
                v, e, dt, p = map(int, partes)
                velocidade.append(v)
                erro.append(e)
                pwm.append(p)
                amostras.append(contador)
                contador += 1

            ser.reset_input_buffer()
        except Exception as ex:
            print("Erro na leitura:", ex)



# Thread de leitura dos dados da serial
t = threading.Thread(target=ler_dados, daemon=True)
t.start()

# Atualização do gráfico
def animar(i):
    # print('entrou')
    ax1.clear()
    ax2.clear()
    ax3.clear()

    ax1.plot(amostras, velocidade, label="Velocidade")
    ax2.plot(amostras, pwm, label="PWM")
    ax3.plot(amostras, erro, label="Erro", color="red")

    ax1.set_ylabel("Velocidade / PWM")
    ax2.set_ylabel("Erro")
    ax3.set_xlabel("Amostras")
    ax1.legend()
    ax2.legend()
    ax3.legend()
    
    ax1.grid(True)
    ax2.grid(True)
    ax3.grid(True)

# Setup do gráfico
fig, (ax1, ax2, ax3) = plt.subplots(3, 1)
ani = animation.FuncAnimation(fig, animar, interval=100)
plt.tight_layout()

# Thread para envio de comandos ao microcontrolador
def entrada_usuario():
    while True:
        comando = input("Digite comando (char): ")
        ser.write(comando.encode())

te = threading.Thread(target=entrada_usuario, daemon=True)
te.start()

# Inicia o gráfico
plt.show()

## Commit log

2024-08-15 initial manipulator urdf
    [Manipulador.xacro, base_cima_1.stl, base_link.stl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]
2024-08-16 manip urdf not working
2024-08-16 areas com pastas separadas
    [Manipulador.xacro, base_cima_1.stl, base_link.stl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]
2024-08-21 manipulador com problemas de gerar a garra pelo moveit
    [Manipulador.ros2_control.xacro, Manipulador.urdf.xacro, Manipulador.xacro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]
2024-08-21 robo spawnando porém não esta rodando a tragetoria planejada
    [Manipulador.xacro, joint_limits.yaml, ros2_controllers.yaml]
2024-08-22 manipulador calculando a trajetória do braço porém com alguns bugs
    [Manipulador.ros2_control.xacro]
2024-09-07 Add: first version of simulation pkg
    [cute_cube.blend, model.sdf, myfirstrobot.urdf.xacro]
2024-09-11 Add&Update: Start to integrating the base_description with navigation pkg
    [Base.xacro, base_link.stl, front_left_wheel_1.stl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]
2024-09-22 Update NAV: Cross-launch-pkgs working with any map in /simulation
    [Base.xacro, car.urdf]
2024-11-20 ADD: Interface pkg STM32+ROS2
    [car.urdf]
2024-12-09 ADD: V0 of STM32G0 firmware
2024-12-10 Update: navigation pkg working in a test urdf
    [car.urdf, cute_cube.blend, omnidirectional_controller.yaml]
2024-12-10 Update: NAV2 pkg working with the right urdf
2024-12-11 Update: Start ros2_control for Gazebo
    [Base.xacro, ros2_control.xacro]
2024-12-11 Update: ros2_control working with omnidirectional
    [Base.xacro, ros2_control.xacro]
2024-12-16 UPDATE: ros2_control working (need to solve the rollers problem of omnidirectional robot)
    [ros2_control.xacro]
2025-01-14 ADD: New USB COMM for STM32U5 && A New MCU <-> Jetson Interface (For USB)
2025-01-27 Update STM firmware enviando a velocidade e a distancia de cada motor (velocidade talvez errada) Update serial interface recebendo as informacoes do stm, porem falta publicar no topico
2025-01-28 add motors msg for serial interface and motors data publisher (not tested all)
2025-01-30 Update stm32 send velocity and position Update ros send pwm to stm32
2025-02-01 Update: Imported from Onshape the new URDF and its working on Gazebo
    [imu.stl, lidar.stl, mdf_motores.stl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]
2025-02-02 UPDATE: URDF with aligned wheels, but planar pluggin doesnt work pretty well
    [mdf_motores.stl, motor.stl, part_1.stl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]
2025-02-05 Add a new setup file for jetson but is incomplete
2025-02-13 Add vision pkg (open camera working)
2025-02-14 Update stm firmware for temporary board
2025-02-15 - Reorganizing folders - Add vision package prototype - Add control package prototype
    [Manipulador.ros2_control.xacro, Manipulador.urdf.xacro, Manipulador.xacro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]
2025-02-15 Add&Update: Organazing the workspace and now URDF is working in the simulation (using Gazebo pluggin, but have ros2 control too)
    [Base.xacro, base_link.stl, car.urdf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]
2025-02-16 Add: First progress with hardware interface ( ps: the package is building with 0 errors :) )
    [diffbot.ros2_control.xacro, diffbot.urdf.xacro, diffbot_controllers.yaml]
2025-02-19 Update: ROS2_CONTROL hardware interface working with stm32, just saving to not lose the progress
    [diffbot.materials.xacro, diffbot.ros2_control.xacro, diffbot.urdf.xacro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]
2025-02-20 Update: Changing diffdrive_arduino hardware interface pkg name to omnidrive_stm32
    [diffbot.materials.xacro, diffbot.ros2_control.xacro, diffbot.urdf.xacro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]
2025-02-20 Delete: Removing wrong hardware interfaces pkgs
    [diffbot.materials.xacro, diffbot.ros2_control.xacro, diffbot.urdf.xacro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]
2025-02-20 Update: Now robot.xacro receive parameters (use_time_sim) to separate when use real robot or simulated robot
    [gazebo_control.xacro, robot.xacro, ros2_control.xacro]
2025-02-20 Update: Changing omnidrive_stm32 pkg to omnicare_control
    [diffbot.materials.xacro, diffbot.ros2_control.xacro, diffbot.urdf.xacro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]
2025-02-20 Update: Changing pkg name (simulation_pkg -> omnicare_simulation)
    [model.sdf]
2025-02-20 Delete: Removing simulation_pkg
    [model.sdf]
2025-02-20 Update&Delete: Fix the load real robot of omnicare_bringup pkg, now is printing the encoders && deleteing omnidrive_stm32 in src/ folder
    [diffbot.materials.xacro, diffbot.ros2_control.xacro, diffbot.urdf.xacro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]
2025-02-20 Update: Fix the STM32 Firmware
    [main.c]
2025-02-20 Update: Fix STM32 Firmware
    [main.c, serial_interface.py]
2025-02-23 Refactor Stm32 code for send only raw encoders value and recive PWM velocity (building but not tested)
2025-02-23 Fix encoders side configuration (building but not tested)
    [main.c]
2025-02-27 add yolo instalation for jetson orin nano
2025-02-27 Fix encoder direction method and serial interface
    [main.c, serial_interface.py]
2025-02-28 Update: STM32 Firmware (Need to fix - hardfault when you try to communicate with the ROS2_CONTROL
2025-03-07 Fix load real robot controller params file path.
    Remove joint state publisher node from load sim robot and comment cmd mux.
    Update setup.py control pkg for use get_package_share_path function
2025-03-07 Fix stm32 code for use with ros2 control
2025-03-07 Fix odometry working but wrong values of velocity
2025-03-07 Remove old control pkg
    [omnidirectional_controller.yaml]
2025-03-10 Update: Start to doing the closed loop in STM32, didnt built the project yet
2025-03-13 Update: STM32 Firmware now is working with only propotional of PID (Need to figure out why our robot become the Tremidinha
2025-03-13 Fix&Update: Fix the last commit && PID with only Kp is working :D
    [main.c]
2025-04-04 Update: Working on serial interface node to plot the motor control to see if works or not (didn't finish yet, just receiving the wanted velocity)
    [serial_interface.py]
2025-04-10 Update: Add Plot node && Fix the serial interface pkg
    [serial_interface.py]
2025-04-11 Update: Change the serial_interface_pkg (plotNode now plot the set speed and real robot speed && serial interface pick all the motor 0 information)
2025-04-11 Update: Fixing the closed loop, now USBX write is sending all informations about Motor 0
2025-04-12 Fix PID and ploting graph
2025-04-12 Update restoring original motor serial msg
2025-04-12 Update Motor graph with PWM, Error and velocity
    [motorGraph.py]
2025-04-19 Update: Fixing some issues on simulation (Frame Rate on pluggins, NAV2 && Cartograph launchs)
2025-05-03 Update&Add: Update the XACRO of the robot (LiDAR link for real LiDAR) && Add Teleop Joy launch
    [robot.xacro]
2025-05-03 Add: Joy Params && Box filter Params && Map of Quinto Andar
2025-05-05 Fix: Fix some robot params for mapping and navigation (verify if robot moves exactly 1m && add laser filter topic to mapping && add base_footprint to ekf config && fix mapping launch)
2025-05-06 Update: Now omnicare bringup real robot, bringup the LiDAR and the teleop (if u want)
2025-05-08 Update: Tuning the params of NAV2 (Need to modify the behavior, and the motor speed)
2025-05-09 Update: Updating the omnidirecional kinematics submodule to the correct branch
2025-05-10 Update: Now bringup have mapping params, for use laser filter
2025-06-02 Fix: Fixing all warnings when you try to compile
    [diffbot_system.cpp]

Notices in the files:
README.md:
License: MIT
